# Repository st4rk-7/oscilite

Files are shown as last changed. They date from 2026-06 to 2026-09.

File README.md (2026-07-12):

# Oscilite

A digital storage oscilloscope built from scratch on an STM32F407. This project covers the full stack of building a real instrument: analog signal conditioning → ADC sampling → DMA → triggering → rendering → custom PCB hardware design.

Currently running as a breadboard prototype with the V2 custom PCB shield designed and ready for fabrication.

<div align="center">
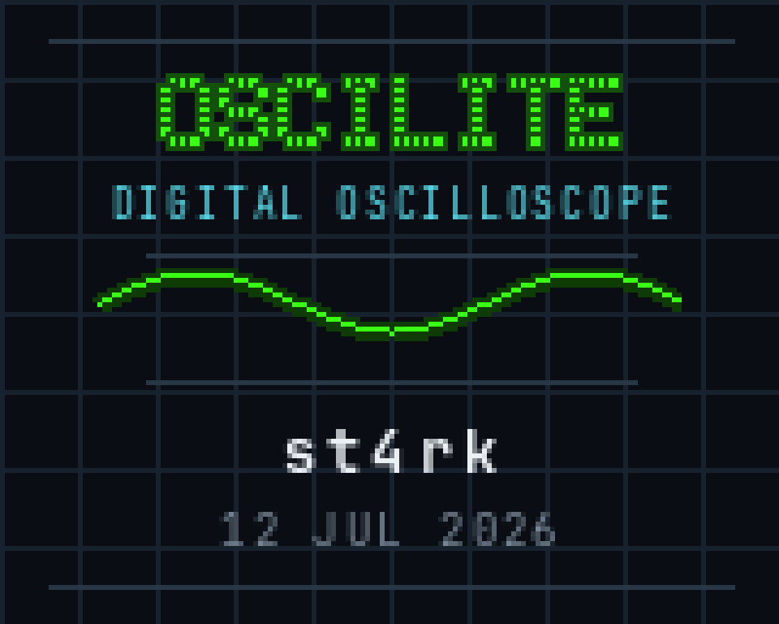
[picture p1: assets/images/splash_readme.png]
Oscilite boot splash
  
  <p><i>The boot splash rendered on the 160×128 ST7735 TFT at power-on.</i></p>
</div>

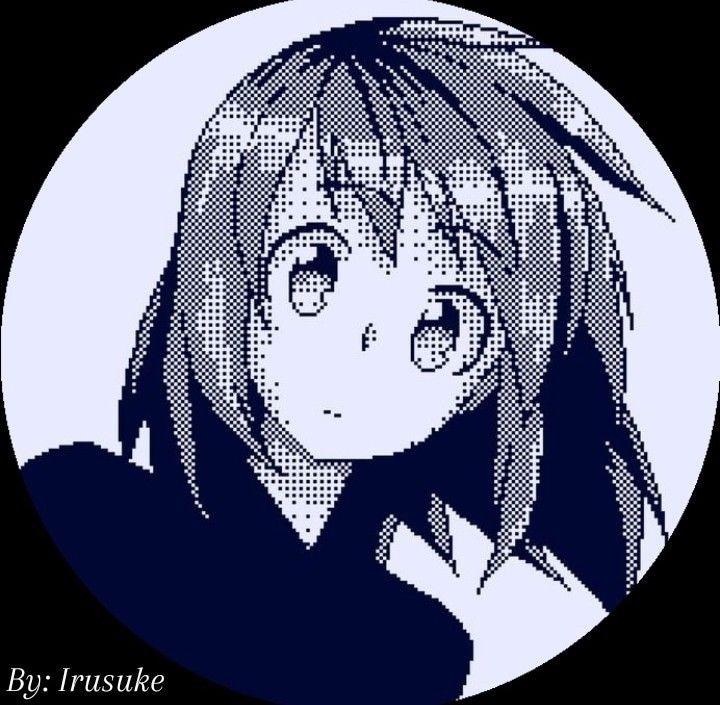
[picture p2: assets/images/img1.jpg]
Oscilite Breadboard Prototype

*The breadboard prototype running live firmware, capturing and displaying a waveform.*

## Features

- **Live waveform display** on an ILI9341 TFT with an 8×6 division graticule.
- **Hardware‑timed sampling** — a timer (TIM3) drives the ADC so every sample lands at a precise interval (timebase).
- **DMA capture** — the ADC streams samples into memory via DMA with zero CPU involvement (circular buffer on DMA2 Stream0).
- **Software triggering** — rising/falling slope with an adjustable trigger level, so the waveform locks in place instead of jittering.
- **Analog frontend** — attenuates and biases the input to safely measure bipolar signals (centered at ~1.65 V) into the MCU's 0–3.3 V ADC.
- **Automatic measurements** — min / max voltage, peak‑to‑peak, and signal frequency, shown on screen.
- **Boot splash screen** generated from an image via a custom Python pipeline.

## The Breadboard Prototype (V1)

The current working prototype proves out the entire software stack and analog theory.

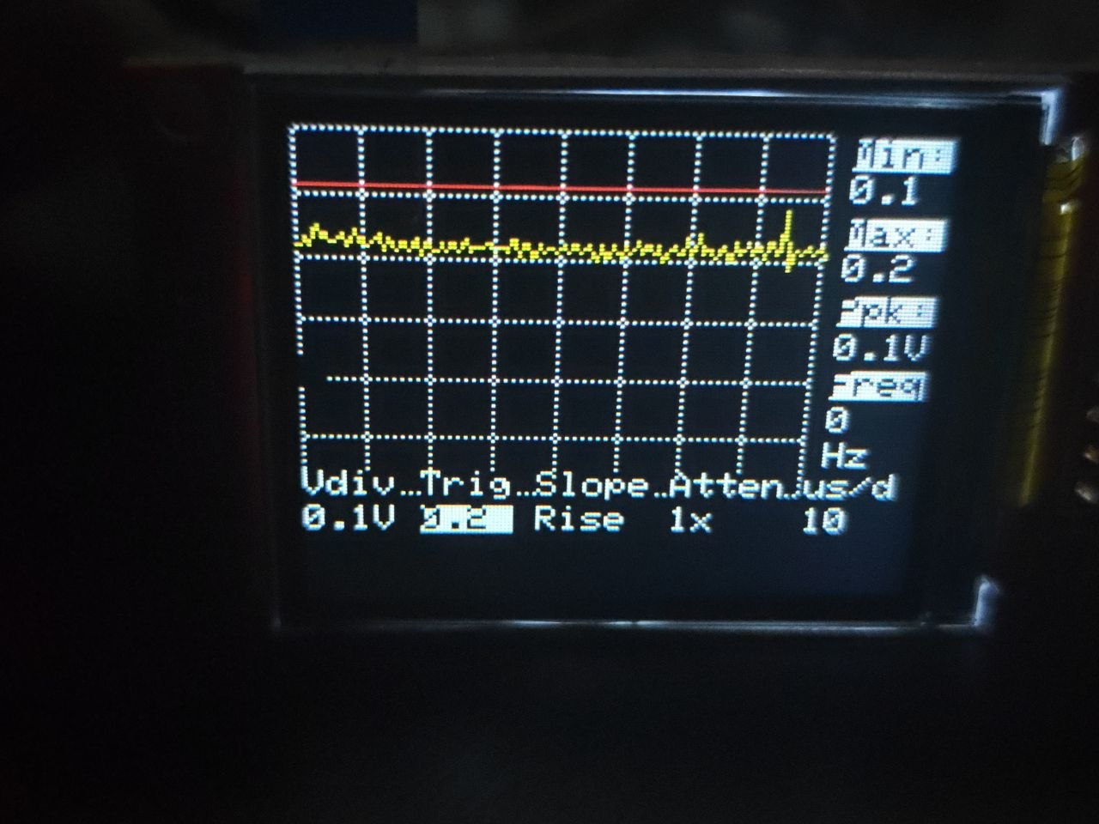
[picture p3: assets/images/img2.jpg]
Full System Setup

*Full system context showing the STM32F407 Discovery board, the analog frontend, and the display.*

**How It Works:**
```
 Input ─▶ Analog Frontend ─▶ ADC (12‑bit) ─▶ DMA ─▶ Sample Buffer ─▶ Trigger ─▶ Display
        (attenuate + bias)   (TIM3‑timed)   (circular)              (align)    (ILI9341)
```

The input signal is attenuated and centered at ~1.65 V using an MCP6002 op-amp buffer circuit so it fits the ADC's 0–3.3 V window. A timer fires the ADC at a fixed rate to set the timebase; the DMA engine moves each sample into a circular buffer without the CPU. The firmware then finds the trigger point (rising or falling through the trigger level) and draws the aligned waveform, computing min/max/Vpp and frequency along the way.

*(A deeper write‑up of the theory is in [`docs/HowItWorks.md`](docs/HowItWorks.md))*

## Hardware Design (V2 PCB)

To move past the breadboard stage, a custom 2-layer PCB shield was designed in KiCad 10. The shield mounts directly onto the STM32F407 dev board headers, carrying the analog frontend, BNC connector, user buttons, and a header for the TFT display.

<div align="center">
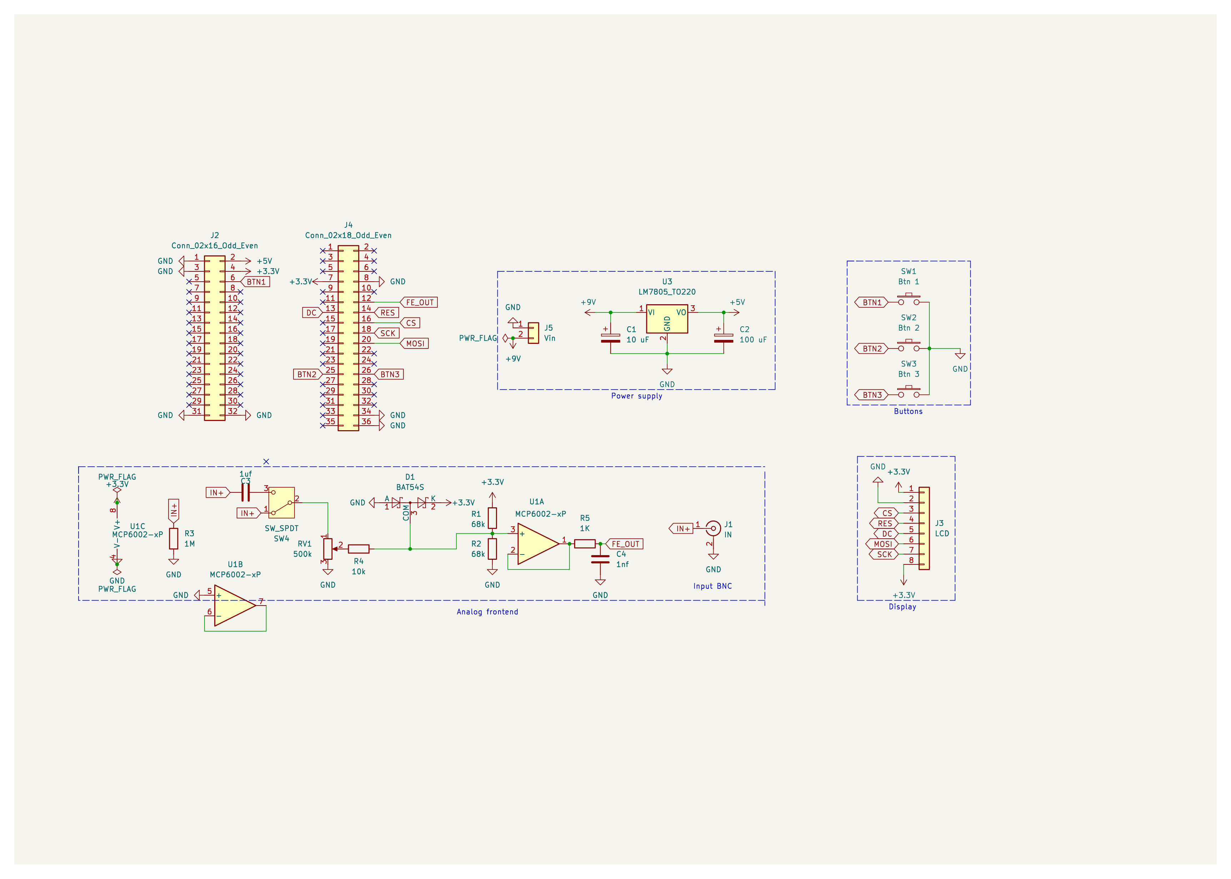
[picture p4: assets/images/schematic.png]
Oscilite Circuit Schematic
  
  <p><i>The analog frontend, power distribution, and UI circuitry.</i></p>
</div>

### PCB Layout and Renders
The board is fully routed, DRC-clean, and the Gerbers are ready for manufacturing.

| Top Copper & Silkscreen | 3D Render (Top) |
|:---:|:---:|
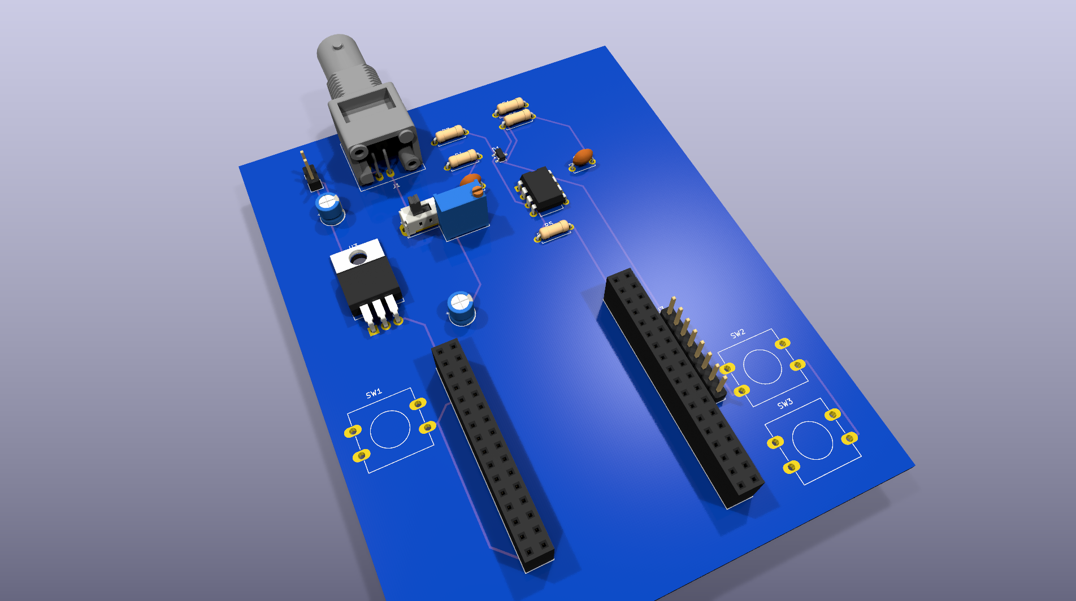
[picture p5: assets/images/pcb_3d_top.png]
|  |  |

| Bottom Copper | 3D Render (Bottom) |
|:---:|:---:|
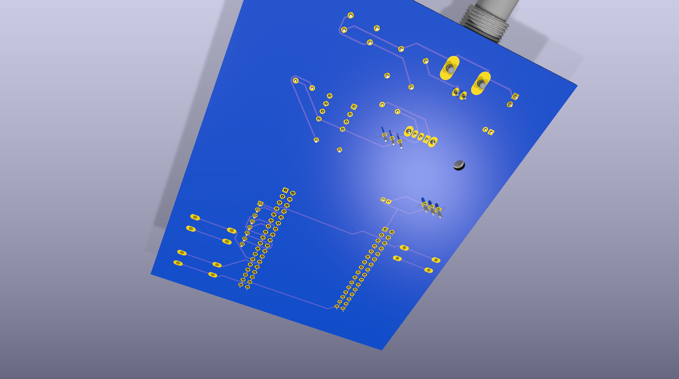
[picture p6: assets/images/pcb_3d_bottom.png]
|  |  |

*Note: The board relies on a dual-header layout designed specifically for the Diymore STM32F407VGT6 development board.*

## Project Structure

```
Core/Src/        Firmware: scope.c, ui.c, wave.c, adc.c, dma.c, tim.c, sandbox.c, main.c
Core/Inc/        Headers (scope.h defines grid, buffer length, trigger constants)
Drivers/         STM32 HAL + CMSIS + Display driver
pcb/fullScope/   KiCad project, layout, DRC reports, Gerbers
docs/            HowItWorks.md, PCB walkthrough
scripts/         Helper scripts (splash image conversion, UI patching)
Scopef407.ioc    STM32CubeMX configuration
```

## Building & Flashing

Prerequisites:
- [STM32CubeMX](https://www.st.com/en/development-tools/stm32cubemx.html) (config is in `Scopef407.ioc`)
- ARM GNU toolchain (`arm-none-eabi-gcc`)
- CMake ≥ 3.22 and Ninja
- A flashing tool: STM32CubeProgrammer, OpenOCD, or st-link

Build:
```bash
# Configure (uses the provided CMake presets)
cmake --preset Debug

# Build
cmake --build build/Debug
```

Flash it with your tool of choice, e.g.:
```bash
st-flash write build/Debug/Scopef407.bin 0x8000000
```

## Project Status & Phases

- **Phase 1 (Complete):** Breadboard prototype, firmware architecture (ADC/DMA/Trigger), and UI rendering.
- **Phase 2 (Current):** Custom PCB shield designed, DRC-verified, and Gerbers generated.
- **Phase 3 (Next):** PCB fabrication, assembly, and testing of the final standalone hardware unit.

This is intentionally a hands-on learning project to understand the full stack of instrument creation, not a precision lab tool.

## Acknowledgments
Built on the STM32 HAL and CMSIS.

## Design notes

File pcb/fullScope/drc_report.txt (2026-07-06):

** Drc report for fullScope.kicad_pcb **
** Created on 2026-06-18T18:27:12 **
** Report includes: Errors, Warnings **

** Found 19 DRC violations **
[solder_mask_bridge]: Front solder mask aperture bridges items with different nets
    Rule: board setup solder mask min width; error
    @(98.5000 mm, 108.0000 mm): PTH pad 1 [BTN1] of SW1
    @(100.0000 mm, 107.6200 mm): PTH pad 7 [unconnected-(J2-Pin_7-Pad7)] of J2
[solder_mask_bridge]: Rear solder mask aperture bridges items with different nets
    Rule: board setup solder mask min width; error
    @(100.0000 mm, 107.6200 mm): PTH pad 7 [unconnected-(J2-Pin_7-Pad7)] of J2
    @(98.5000 mm, 108.0000 mm): PTH pad 1 [BTN1] of SW1
[solder_mask_bridge]: Front solder mask aperture bridges items with different nets
    Rule: board setup solder mask min width; error
    @(98.5000 mm, 108.0000 mm): PTH pad 1 [BTN1] of SW1
    @(97.4600 mm, 107.6200 mm): PTH pad 8 [unconnected-(J2-Pin_8-Pad8)] of J2
[solder_mask_bridge]: Rear solder mask aperture bridges items with different nets
    Rule: board setup solder mask min width; error
    @(97.4600 mm, 107.6200 mm): PTH pad 8 [unconnected-(J2-Pin_8-Pad8)] of J2
    @(98.5000 mm, 108.0000 mm): PTH pad 1 [BTN1] of SW1
[solder_mask_bridge]: Front solder mask aperture bridges items with different nets
    Rule: board setup solder mask min width; error
    @(98.5000 mm, 113.0000 mm): PTH pad 2 [GND] of SW1
    @(97.4600 mm, 112.7000 mm): PTH pad 12 [unconnected-(J2-Pin_12-Pad12)] of J2
[solder_mask_bridge]: Front solder mask aperture bridges items with different nets
    Rule: board setup solder mask min width; error
    @(100.0000 mm, 112.7000 mm): PTH pad 11 [unconnected-(J2-Pin_11-Pad11)] of J2
    @(98.5000 mm, 113.0000 mm): PTH pad 2 [GND] of SW1
[solder_mask_bridge]: Rear solder mask aperture bridges items with different nets
    Rule: board setup solder mask min width; error
    @(98.5000 mm, 113.0000 mm): PTH pad 2 [GND] of SW1
    @(100.0000 mm, 112.7000 mm): PTH pad 11 [unconnected-(J2-Pin_11-Pad11)] of J2
[solder_mask_bridge]: Rear solder mask aperture bridges items with different nets
    Rule: board setup solder mask min width; error
    @(98.5000 mm, 113.0000 mm): PTH pad 2 [GND] of SW1
    @(97.4600 mm, 112.7000 mm): PTH pad 12 [unconnected-(J2-Pin_12-Pad12)] of J2
[hole_to_hole]: Drilled hole too close to other hole (board setup constraints min 0.2495 mm; actual 0.0000 mm)
    Rule: board setup constraints; error
    @(98.5000 mm, 108.0000 mm): PTH pad 1 [BTN1] of SW1
    @(97.4600 mm, 107.6200 mm): PTH pad 8 [unconnected-(J2-Pin_8-Pad8)] of J2
[hole_to_hole]: Drilled hole too close to other hole (board setup constraints min 0.2495 mm; actual 0.0000 mm)
    Rule: board setup constraints; error
    @(97.4600 mm, 112.7000 mm): PTH pad 12 [unconnected-(J2-Pin_12-Pad12)] of J2
    @(98.5000 mm, 113.0000 mm): PTH pad 2 [GND] of SW1
[copper_edge_clearance]: Board edge clearance violation
    Rule: board setup constraints edge; error
    @(74.0000 mm, 34.0000 mm): Rectangle on Edge.Cuts
    @(165.5000 mm, 136.0000 mm): PTH pad 1 [BTN3] of SW3
[copper_edge_clearance]: Board edge clearance violation
    Rule: board setup constraints edge; error
    @(74.0000 mm, 34.0000 mm): Rectangle on Edge.Cuts
    @(165.5000 mm, 141.0000 mm): PTH pad 2 [GND] of SW3
[copper_edge_clearance]: Board edge clearance violation
    Rule: board setup constraints edge; error
    @(74.0000 mm, 34.0000 mm): Rectangle on Edge.Cuts
    @(165.5000 mm, 120.0000 mm): PTH pad 1 [BTN2] of SW2
[copper_edge_clearance]: Board edge clearance violation
    Rule: board setup constraints edge; error
    @(74.0000 mm, 34.0000 mm): Rectangle on Edge.Cuts
    @(165.5000 mm, 125.0000 mm): PTH pad 2 [GND] of SW2
[courtyards_overlap]: Courtyards overlap
    Rule: board setup constraints courtyard; error
    @(86.0000 mm, 108.0000 mm): Footprint SW1
    @(100.0000 mm, 100.0000 mm): Footprint J2
[shorting_items]: Items shorting two nets (nets BTN1 and unconnected-(J2-Pin_7-Pad7))
    Local override; error
    @(98.5000 mm, 108.0000 mm): PTH pad 1 [BTN1] of SW1
    @(100.0000 mm, 107.6200 mm): PTH pad 7 [unconnected-(J2-Pin_7-Pad7)] of J2
[shorting_items]: Items shorting two nets (nets BTN1 and unconnected-(J2-Pin_8-Pad8))
    Local override; error
    @(98.5000 mm, 108.0000 mm): PTH pad 1 [BTN1] of SW1
    @(97.4600 mm, 107.6200 mm): PTH pad 8 [unconnected-(J2-Pin_8-Pad8)] of J2
[shorting_items]: Items shorting two nets (nets GND and unconnected-(J2-Pin_12-Pad12))
    Local override; error
    @(98.5000 mm, 113.0000 mm): PTH pad 2 [GND] of SW1
    @(97.4600 mm, 112.7000 mm): PTH pad 12 [unconnected-(J2-Pin_12-Pad12)] of J2
[shorting_items]: Items shorting two nets (nets GND and unconnected-(J2-Pin_11-Pad11))
    Local override; error
    @(98.5000 mm, 113.0000 mm): PTH pad 2 [GND] of SW1
    @(100.0000 mm, 112.7000 mm): PTH pad 11 [unconnected-(J2-Pin_11-Pad11)] of J2

** Found 4 unconnected pads **
[unconnected_items]: Missing connection between items
    Local override; error
    @(98.5000 mm, 113.0000 mm): PTH pad 2 [GND] of SW1
    @(86.0000 mm, 113.0000 mm): PTH pad 2 [GND] of SW1
[unconnected_items]: Missing connection between items
    Local override; error
    @(98.5000 mm, 113.0000 mm): PTH pad 2 [GND] of SW1
    @(100.0000 mm, 138.1000 mm): Track [GND] on B.Cu, length 2.5400 mm
[unconnected_items]: Missing connection between items
    Local override; error
    @(100.0000 mm, 100.0000 mm): Track [GND] on F.Cu, length 2.5400 mm
    @(98.5000 mm, 113.0000 mm): PTH pad 2 [GND] of SW1
[unconnected_items]: Missing connection between items
    Local override; error
    @(98.5000 mm, 108.0000 mm): PTH pad 1 [BTN1] of SW1
    @(94.5400 mm, 108.0000 mm): Track [BTN1] on B.Cu, length 4.1295 mm

** Found 0 Footprint errors **

** Ignored checks **
    - Footprint has no courtyard defined
    - Track endpoint not centered on via
    - Tuning profile track geometries
    - Footprint doesn't match symbol's footprint filters
    - Silkscreen clearance
    - Silkscreen clipped by solder mask
    - PTH inside courtyard
    - NPTH inside courtyard

** End of Report **

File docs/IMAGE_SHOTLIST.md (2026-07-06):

# Oscilite — Image Shot List

Capture list for the README + LinkedIn / GitHub / portfolio publish.
Goal: show it **works**, show it's **real hardware**, and show the **engineering depth** (firmware → analog → PCB → fab).

Save everything into `assets/images/`. Suggested final filenames are in each item.
Existing files: `img1.jpg`, `img2.jpg` (re-slot or rename into the list below).

> **⚠️ No physical STM32 on hand right now.** Everything in **GROUP A** below is
> generated on your computer (KiCad, diagrams) and can be captured *today* — that
> covers all of TIER 1 except the live-screen photo, plus most depth shots.
> Everything in **GROUP B** needs the powered-up board and waits until you have it.
> You can publish a strong README/portfolio post with Group A alone; add Group B later.

---

## ✅ GROUP A — Capturable now (no hardware needed)

These are the high-value, "real engineering" shots and they're all free to produce:

- [ ] **PCB 3D render — top** — `pcb_3d_top.png`
  KiCad → open `pcb/fullScope/fullScope.kicad_pcb` → View → **3D Viewer** (Alt+3) → File → Export Current View → PNG. Use this as the **hero image** until you have a real photo.

- [ ] **PCB 3D render — bottom** — `pcb_3d_bottom.png`
  In the 3D viewer, drag to flip the board. Shows bottom-copper (blue) routing.

- [ ] **PCB 2D layout (routed)** — `pcb_layout.png`
  KiCad PCB editor, all copper layers on, traces visible. Screenshot or File → Export → SVG/PNG. Shows the routing work.

- [ ] **Schematic overview** — `schematic.png`
  From `fullScope.kicad_sch`: File → Plot → PDF (or screenshot the sheet). Signals "designed circuit, not a breadboard hack."

- [ ] **Analog frontend close-up** — `frontend.png`
  Crop just the frontend section of the schematic (±3.3V attenuator / op-amp / 1.65V bias). The cleverest electronics in the project. (Also see `docs/frontend.pdf`.)

- [ ] **Gerber / fab preview** — `gerber_preview.png`
  Upload `pcb/fullScope/fullScope_gerbers.zip` to an online viewer (JLCPCB preview, or use KiCad's Gerber Viewer) and screenshot. Proves it's manufacturing-ready.

- [ ] **Block diagram** — `block_diagram.png`
  Signal flow: `Input → Analog Frontend → ADC → DMA → Buffer → Display`. Make in draw.io / Excalidraw. The single most useful image for a reader skimming the README — and the README already has this as ASCII, so you're just prettifying it.

- [ ] **(Optional) DRC clean screenshot** — `drc_clean.png`
  KiCad → Inspect → Design Rules Checker → Run. Screenshot the "0 violations" result. Strong credibility for an embedded/hardware portfolio.

> With Group A you have: a hero (3D render), the layout, schematic, frontend, fab proof,
> and a diagram — enough for a complete README and LinkedIn carousel **today**.

---

## ⏳ GROUP B — Needs the physical board (capture later)

- [ ] **Hero shot (real)** — `hero.jpg` — assembled scope powered on showing a waveform. Swap in over the 3D render once you have it.
- [ ] **Live waveform close-up** — `waveform_screen.jpg` — display showing a trace + grid. Feed a 1 kHz square from a function gen or another MCU PWM pin.
- [ ] **Wiring / bring-up shot** — `bringup.jpg` — STM32F407 + display + frontend on jumper wires. `img1.jpg`/`img2.jpg` may already be this — check them.
- [ ] **UI / menu shot** — `ui_menu.jpg` — on-screen timebase/volt/trigger controls.
- [ ] **Splash screen** — `splash.jpg` — the boot splash (from your `splash.h` + `img2splash.py` pipeline).
- [ ] **Trigger demo (2 photos)** — `trigger_unstable.jpg` / `trigger_stable.jpg` — same signal, trigger off vs on. Great LinkedIn carousel.
- [ ] **Multiple waveforms grid** — `waveforms_montage.jpg` — sine/square/triangle/noise, 2x2.
- [ ] **Size/scale shot** — `scale.jpg` — board next to a coin/hand.

> **Check `assets/images/img1.jpg` and `img2.jpg` first** — if they're already bench/bring-up
> photos, you may already have part of Group B covered.

---

## (original tiers, for reference)

## TIER 1 — Must have (the README cannot land without these)

- [ ] **Hero shot** — `hero.jpg`
  The assembled scope powered on, displaying a clean waveform (sine or square). Slightly angled, good lighting, plain background. This is the LinkedIn thumbnail and the top of the README. Make it the best photo you take.

- [ ] **Live waveform close-up** — `waveform_screen.jpg`
  Tight shot of the display showing a recognizable trace with the grid/graticule visible. Proves the DSO actually samples and renders. Feed it a known signal (e.g. 1 kHz square from a function gen or another MCU PWM pin).

- [ ] **PCB 3D render — top** — `pcb_3d_top.png`
  KiCad → View → **3D Viewer** → export PNG. Top of `pcb/fullScope/fullScope.kicad_pcb`. Looks professional and costs nothing to produce.

- [ ] **PCB 2D layout (routed)** — `pcb_layout.png`
  KiCad PCB editor, all copper layers visible, traces routed. Export via File → Export → SVG/PNG, or screenshot. Shows the 179-trace routing work.

---

## TIER 2 — Strongly recommended (depth + credibility)

- [ ] **PCB 3D render — bottom** — `pcb_3d_bottom.png`
  Flip side in 3D viewer. Shows the bottom-copper (blue) routing.

- [ ] **Schematic overview** — `schematic.png`
  Export the full sheet from `fullScope.kicad_sch` (File → Plot → PDF, or screenshot). Even as a thumbnail it signals "this is a designed circuit, not a breadboard hack."

- [ ] **Analog frontend close-up** — `frontend.png`
  Crop of just the analog-frontend section of the schematic (the ±3.3V attenuator / op-amp / 1.65V bias). This is the cleverest electronics in the project — call it out. (Ref: `docs/frontend.pdf` mentioned in HowItWorks.md.)

- [ ] **Wiring / bring-up shot** — `bringup.jpg`
  STM32F407 + display + frontend wired on the bench (jumper wires / dev board stage). Tells the "before the PCB" story. `img1.jpg`/`img2.jpg` may already be this.

- [ ] **UI / menu shot** — `ui_menu.jpg`
  The on-screen UI: timebase / voltage / trigger controls or the menu. Shows it's a usable instrument, not just a trace renderer.

- [ ] **Splash screen** — `splash.jpg`
  The boot splash on the display. You built a `splash.h` + `img2splash.py` pipeline — worth a sentence and a photo.

---

## TIER 3 — Nice to have (storytelling / extra polish)

- [ ] **Trigger demo (2 photos)** — `trigger_stable.jpg`, `trigger_unstable.jpg`
  Same signal, trigger off vs on (jittery trace vs locked trace). Great for a LinkedIn carousel — visually demonstrates what triggering does.

- [ ] **Multiple waveforms grid** — `waveforms_montage.jpg`
  Sine / square / triangle / noise in a 2x2 montage. Shows range. Good portfolio filler.

- [ ] **Size/scale shot** — `scale.jpg`
  Scope next to a coin or hand for sense of scale. Humanizes the build.

- [ ] **Gerber / fab preview** — `gerber_preview.png`
  Screenshot of the gerbers in an online viewer (e.g. JLCPCB upload preview or KiCad gerber viewer). Proves it's manufacturing-ready.

- [ ] **Block diagram** — `block_diagram.png`
  Signal flow: `Input → Analog Frontend → ADC → DMA → Buffer → Display`. Make in draw.io / Excalidraw. The single most useful image for a reader skimming the README. (Optional but high value.)

---

## Capture tips
- **One consistent background + lighting** for all physical photos → looks like a deliberate project, not random snaps.
- Shoot landscape (16:9) — fits README and LinkedIn better than portrait.
- For screen photos: dim room, lower display brightness slightly, focus on the screen to avoid moire/glare.
- KiCad renders export at high res for free — lean on them; they carry the README even before you reshoot hardware photos.

## Where they go
- **README hero block:** `hero.jpg` + one-line tagline.
- **"It works" section:** `waveform_screen.jpg`, `ui_menu.jpg`, trigger demo.
- **"Hardware design" section:** `pcb_3d_top.png`, `pcb_layout.png`, `schematic.png`, `frontend.png`.
- **"How it works" section:** `block_diagram.png` (pairs with `docs/HowItWorks.md`).
- **LinkedIn post:** lead with `hero.jpg`, then a 3–5 image carousel (waveform, PCB 3D, schematic, trigger demo).

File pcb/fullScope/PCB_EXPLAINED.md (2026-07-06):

# pillScopePlus PCB — Everything Explained (Beginner's Guide)

This document explains, in plain language, everything that happened to turn your
oscilloscope schematic into a finished, manufacturable circuit board — starting
from the moment you were hand-drawing red traces, all the way to the Gerber files
ready for the factory.

Read it top to bottom. Each section builds on the last. If anything is unclear,
ask and we'll expand it.

---

## 0. The big picture: what is a PCB and what were we doing?

A **PCB (Printed Circuit Board)** is the green (or any color) board inside every
electronic device. Instead of connecting parts with loose wires, a PCB has thin
lines of copper baked onto it that carry electricity between the components.

Designing one has a fixed workflow. We had already done the first parts before
today:

1. **Schematic** — a diagram of *what connects to what* (done earlier).
2. **Footprints** — telling the software the real physical size/shape of each part (done earlier).
3. **Placement** — arranging the parts physically on the board ← *we redid this today*.
4. **Routing** — drawing the copper lines that connect the parts ← *the big job today*.
5. **DRC** — an automatic check that the board has no mistakes ← *today*.
6. **Gerbers** — the final files you send to the factory ← *today*.

You were stuck partway through step 4 (routing). Today we finished steps 3–6.

---

## 1. The vocabulary you asked about

Before the story, here are the words. Keep coming back to this section.

### Layers: F.Cu, B.Cu, Edge.Cuts

A PCB is like a sandwich with multiple layers. Yours is a **2-layer board** — it
has copper on the **top** and on the **bottom**. The software draws each layer in
a different color:

| Name | Means | Color on screen | What it is |
|---|---|---|---|
| **F.Cu** | **F**ront **Cu** (copper) | **Red** | The copper wiring on the **top** of the board |
| **B.Cu** | **B**ack **Cu** (copper) | **Blue** | The copper wiring on the **bottom** of the board |
| **Edge.Cuts** | Edge / cuts | **Yellow** | The *outline* — where the factory physically cuts the board out |

> **"Cu"** is the chemical symbol for copper. That's why copper layers end in `.Cu`.

So when you asked **"why are some wires blue?"** — those blue lines are traces on
the **bottom** copper layer (B.Cu). The red ones are on the **top** (F.Cu). Having
two layers means wires can cross each other without touching: one goes over the
top, the other underneath, like a road bridge over another road.

### Trace (a.k.a. track)

A **trace** is one line of copper that carries electricity from one point to
another. It replaces a wire. "Routing" = drawing all the traces.

### Pad

A **pad** is the little metal spot where a component's leg gets soldered. Traces
connect pad to pad. On your board most pads are **through-hole** — they have a
drilled hole so a component leg pokes through and is soldered on the back.

### Ratsnest (the thin lines you saw before routing)

Before you route, the software draws thin straight "rubber-band" lines showing
*which pads need to be connected*. These are called the **ratsnest** (or airwires).
They are **not** real wires — just hints. Your whole routing job was to replace
each thin ratsnest line with a real copper trace. When you draw the trace, the
matching ratsnest line disappears.

### Net

A **net** is a group of pads that all need to be connected together (because the
schematic says so). For example, every pad that should connect to "+3.3V" is on
the `+3.3V` net. "GND" is the net for ground. Routing = connecting every pad on
each net with copper.

---

## 2. The story, step by step (from your red traces to the finish)

### Where you started: hand-drawing red traces

When you pressed **`X`** in KiCad and clicked pad-to-pad, you were **manually
routing** — drawing copper traces by hand, one at a time. The red line that
appeared was a real trace on the top copper layer (F.Cu). You successfully
connected a few (like the +3.3V trace) — that proved you understood the idea:
**trace over each ratsnest line, pad to pad.**

### The problem we hit: bad placement made routing impossible

You found that many traces were impossible to route cleanly. **This was not your
fault.** The components were arranged badly. Two specific problems:

- The **display header (J3)** was on the far *left* of the board, but every wire
  it needed went to **J4 on the right** — so 6 wires had to cross the *entire*
  board.
- Two **buttons (SW2, SW3)** were on the left, but their signals went to J4 on
  the right too.

When parts that connect to each other are far apart, their wires cross everything
and tangle. The professional rule is: **good placement makes routing easy; bad
placement makes it impossible.** So we fixed the placement first.

### What I did: re-organized the components (Step 3 redone)

I rearranged all 22 components into logical **clusters**, so parts that connect to
each other sit near each other:

- **Power section** (voltage regulator + capacitors) grouped in the top-left.
- **Analog frontend** (the BNC input → op-amp chain) flowing left-to-right across
  the top.
- **Display header (J3)** moved right next to **J4** — killing those 6 cross-board wires.
- **Buttons** moved next to the headers they connect to.

This is why the tangle calmed down dramatically after the re-placement.

### Then: auto-routing with Freerouting (Step 4 finished)

Instead of you hand-drawing all ~19 connections, we used a program called
**Freerouting** to draw all the copper traces automatically. (Explained in detail
in Section 5.) It routed the whole board in about 2 seconds — that's the **179
traces**, both red (top) and blue (bottom), now on your board.

### Why I asked you to make changes twice

You asked why I made you redo things twice. Here's the honest answer:

When I first re-placed the components, I **underestimated the physical size of the
buttons**. A push-button is about 12 mm wide with pads sticking out 14 mm from its
anchor point — bigger than my first estimate. So:

- **1st fix:** A button (SW1) ended up physically *overlapping* the J2 header —
  their holes literally landed on the same spot. The DRC check caught it. I moved
  the buttons away and we re-routed.
- **2nd fix:** After that, two buttons (SW2, SW3) were still only 10 mm apart, but
  they need ~15 mm so their bodies don't physically collide. DRC caught that too.
  I spaced them out and we re-routed one last time.

Each time we moved parts, the old traces no longer lined up, so we had to re-route
— that's why you exported/imported a few times. It wasn't wasted; it was the
normal "check → fix → re-check" loop that catches real manufacturing problems
*before* you spend money. The end result: a board with **zero errors**.

### Finally: DRC clean → Gerbers exported (Steps 5 & 6)

After the last fix, the automatic check (DRC) reported **0 errors and 0 missing
connections**. That was our agreed stopping point. Then I exported the **Gerber**
files (Section 8) — the package you send to a factory like JLCPCB.

---

## 3. What did you do with the grounds? (your question)

**Ground (GND)** is the common "0 volts" reference that almost every part connects
to — it's the single biggest net on any board (tons of pads need ground).

There are two ways to connect all the ground pads:

1. **Route them as traces** — draw a copper line to each ground pad like any other
   net.
2. **Copper pour** — flood a whole area of the board with copper and let every
   ground pad touch it (Section 7).

**What we actually did:** Freerouting connected all the ground pads using normal
**traces** (option 1). The DRC check confirmed every single ground pad is properly
connected (0 unconnected). So ground is *fully handled*.

Earlier in the process I had planned to use a copper pour for ground (option 2),
which is why you saw "ground pour" in our step list. But since the auto-router
already connected every ground pad with traces, **the pour became unnecessary** —
the board is complete and correct without it. A pour would be a nice-to-have for
noise reduction, not a requirement. We correctly skipped it.

---

## 4. Why are some wires blue? (your question)

Because your board has **two copper layers**, and the software color-codes them:

- **Red wires = top copper (F.Cu)**
- **Blue wires = bottom copper (B.Cu)**

When two wires need to cross without touching, the router puts one on top (red)
and one on the bottom (blue) so they pass over/under each other — like a highway
overpass. On your through-hole board, the component legs go through the whole
board, so a trace can connect on either the red or the blue layer at the same pad
without needing extra holes. That's why there are no "vias" (layer-change holes) —
the through-hole pads already bridge both layers.

---

## 5. What is Freerouting and what is it used for? (your question)

**Freerouting** is a free, open-source **auto-router** — a program that draws all
the copper traces on a PCB automatically, so you don't have to click each one by
hand.

### Why we used it

Hand-routing your board meant manually drawing ~19 connections, and you found it
slow and frustrating ("super clunky"). An auto-router does the same job in
seconds. With your now-clean placement, it did an excellent job.

### How it works (the DSN → SES dance)

Freerouting is a separate program from KiCad, so they hand files back and forth:

1. **KiCad exports a `.dsn` file** (`File → Export → Specctra DSN`). This `.dsn`
   describes your board to Freerouting: where every pad is, the board outline, and
   which pads need connecting (the nets). Think of it as "here's the puzzle."
2. **Freerouting reads the `.dsn`, solves the routing**, trying thousands of trace
   paths until everything is connected without crossings or rule violations. I ran
   this on the command line:
   `java -jar freerouting.jar -de fullScope.dsn -do fullScope.ses`
3. **Freerouting writes a `.ses` file** (a "session" file). This is its *answer* —
   the list of all the trace paths it figured out.
4. **KiCad imports the `.ses`** (`File → Import → Specctra Session`), which draws
   all those traces onto your real board.

That's the whole loop: **KiCad → .dsn → Freerouting → .ses → KiCad.** Every time
we moved components, we ran this loop again so the routing matched the new
positions.

> **"java -jar"**: Freerouting is written in the Java language, so it runs with the
> `java` command. You already had Java installed, which is why it worked.

---

## 6. How my "automation scripting" works (your question)

A KiCad PCB file (`fullScope.kicad_pcb`) is actually a **text file**. If you open
it in a text editor, it's a long list describing every component, its position,
every trace, etc., written in a format with lots of parentheses, like:

```
(footprint "Button"
    (at 78 104)        ← this line is the component's X,Y position
    ...
)
```

Because it's text, I can read and edit it with small **scripts** (tiny programs,
written in Python). Here's what I used scripting for:

- **Reading the board:** my scripts scanned the file to list every component, its
  position, its pads, and which net each pad belongs to. That's how I figured out
  the "J3 is far from J4" problem mathematically.
- **Re-placing components:** to move a part, my script found its `(at X Y)` line
  and changed the numbers. Moving 22 components by hand would be slow and
  error-prone; a script does it instantly and exactly.
- **Checking for overlaps:** before applying a new layout, my script calculated
  each component's real size and checked that none would physically collide — so
  we'd catch problems *before* opening KiCad.
- **Clearing old traces:** when we re-placed parts, the old traces were wrong, so a
  script deleted all the `(segment ...)` lines (each trace is a "segment") to give
  a clean slate for re-routing.

> **Important caution we respected:** editing the file directly is powerful but
> risky — one wrong character can corrupt the board. That's why I always made a
> **backup first** (you'll see `.bak_...` files in the folder), and why we did the
> *routing* with Freerouting + the KiCad GUI rather than hand-writing traces into
> the file. We even tested it: I tried writing one trace directly into the file,
> it didn't take (your KiCad version uses a new format), so we wisely switched to
> the GUI/Freerouting approach instead.

---

## 7. What does "pouring" / copper pour mean? (your question)

A **copper pour** (also called a "filled zone" or "ground plane") is when you
flood an entire region of the board with a solid sheet of copper, instead of thin
traces.

It's mainly used for **ground**. Instead of running a separate ground trace to
every part, you pour copper across the whole board and every ground pad just
touches it. Benefits:

- Every ground pad connects automatically.
- The big copper sheet reduces electrical noise (good for sensitive analog parts
  like your op-amp).

**We did not need it** on your board, because the auto-router already connected
every ground pad with traces (see Section 3). The board is complete without a
pour. You could add one later as a polish step, but it's optional.

---

## 8. What is DRC? What is a drill file? What are Gerbers? (your questions)

These are the final three concepts — the "is it correct?" check and the "send to
factory" files.

### DRC — Design Rule Check

**DRC** is an automatic inspector. You press a button and the software checks your
whole board against the manufacturing rules and reports every mistake, such as:

- Two traces too close together (could short circuit).
- A drilled hole too close to another hole.
- A connection that was never routed (a "missing wire").
- A part hanging off the edge of the board.

**This is what caught the button problems.** Each time, DRC told us exactly what
was wrong and where. When DRC finally reported **"0 violations, 0 unconnected
items,"** it meant the board is electrically correct and manufacturable. That was
our finish line.

### Drill file

The factory needs to know **where to drill holes** (for every through-hole part
leg) and **how big** each hole is. The **drill file** (`fullScope.drl`) is a list
of all those hole positions and sizes. The drilling machine reads it directly.

### Gerbers

**Gerber files** are the universal language of PCB factories. Each Gerber file
describes **one layer** of your board as precise shapes the factory machines can
reproduce. Your export produced one file per layer, including:

| File ending | What it describes |
|---|---|
| `.gtl` / `-F_Cu` | Top copper (the red traces) |
| `.gbl` / `-B_Cu` | Bottom copper (the blue traces) |
| `.gts` / `.gbs` | Solder mask (the green coating, with gaps at pads) |
| `.gto` / `.gbo` | Silkscreen (the white text/labels) |
| `.gm1` / `-Edge_Cuts` | The board outline (where to cut) |
| `.drl` | The drill holes |

Together, these files are a complete recipe for building your exact board. I
bundled them into **`fullScope_gerbers.zip`** — that single zip is what you upload
to a manufacturer like JLCPCB, and they ship you the physical board.

---

## 9. Where things stand & what's left

- ✅ Board is fully placed, routed, and **passes DRC with zero errors**.
- ✅ Gerbers + drill files are exported and zipped:
  `pcb/fullScope/fullScope_gerbers.zip`
- ⚠️ **Before ordering:** measure the real distance between the two pin-header rows
  on your physical Diymore STM32 board with calipers, and confirm the J2↔J4
  spacing matches (~35.6 mm was an estimate). This is the one thing we couldn't
  verify without the board in hand. See `FABRICATION_TODO.md`. If it's off, the
  board won't plug together.

That's the entire journey. You took a circuit from a schematic to a
factory-ready board — placement, routing, verification, and output files. That's
the full PCB design skill in miniature.

---

## 10. Quick glossary (one-line reminders)

- **PCB** — the physical circuit board.
- **Trace / track** — a copper line that connects parts (replaces a wire).
- **Pad** — metal spot where a part is soldered.
- **Net** — a group of pads that must be connected (e.g. GND, +3.3V).
- **Ratsnest** — thin hint-lines showing what still needs connecting.
- **F.Cu (red)** — top copper layer. **B.Cu (blue)** — bottom copper layer.
- **Edge.Cuts (yellow)** — the board outline.
- **Placement** — arranging components physically.
- **Routing** — drawing the traces.
- **Freerouting** — a program that routes automatically.
- **DSN / SES** — the files KiCad and Freerouting exchange.
- **Copper pour** — a solid sheet of copper, usually for ground.
- **DRC** — automatic error check of the whole board.
- **Drill file** — list of hole positions/sizes.
- **Gerbers** — the per-layer files you send to the factory.
- **Via** — a small plated hole that moves a trace between layers (your board
  didn't need any, because through-hole pads already bridge both layers).

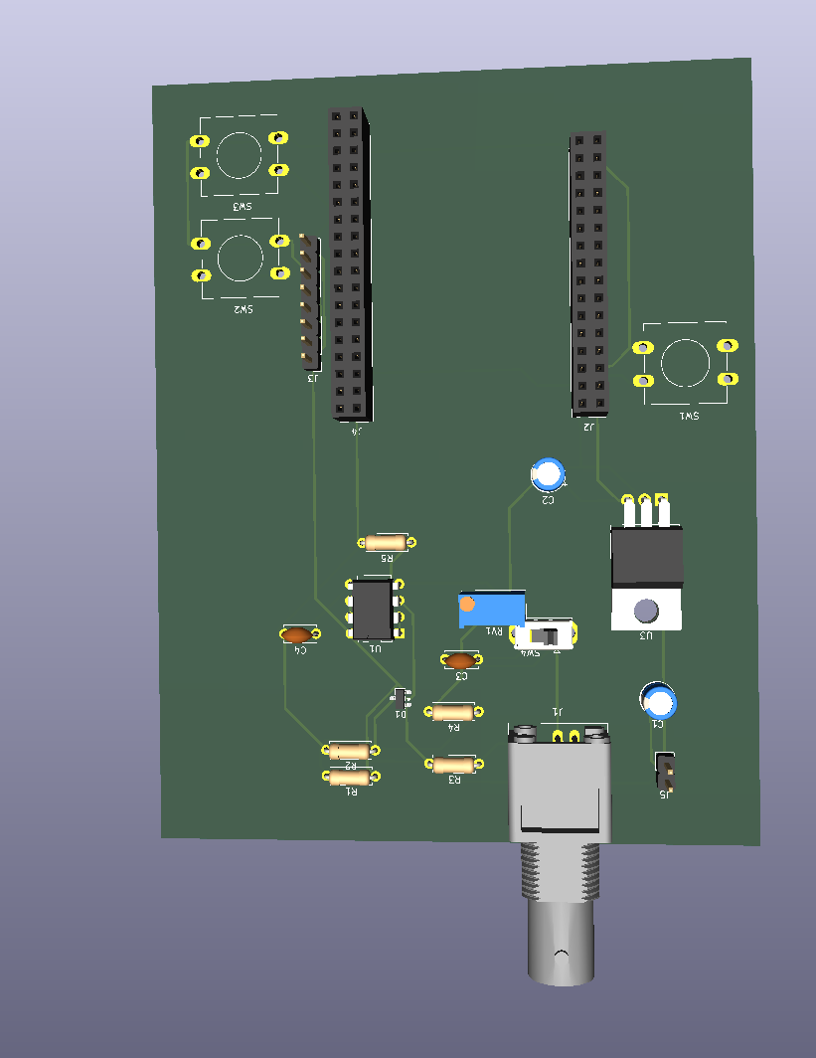
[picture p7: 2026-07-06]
pcb/fullScope/imgs/fullScope.png

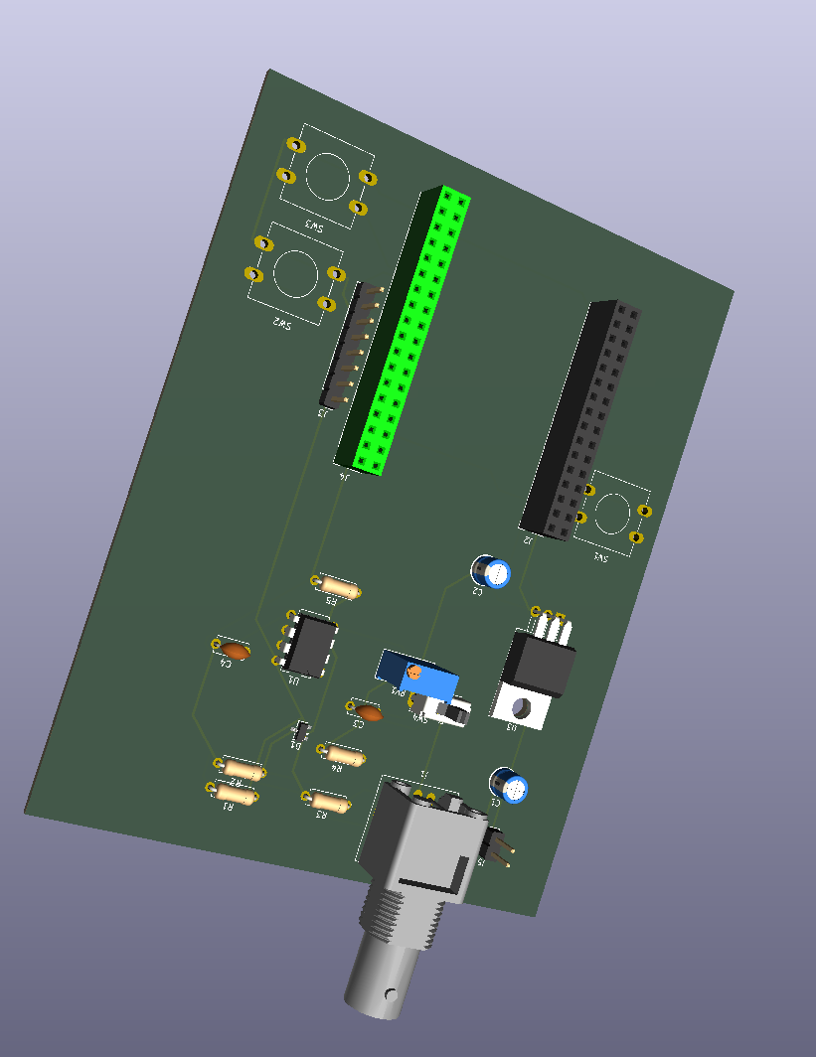
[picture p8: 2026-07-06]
pcb/fullScope/imgs/fullScope2.png

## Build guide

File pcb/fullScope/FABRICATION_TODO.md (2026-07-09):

# FABRICATION TODO — Header Spacing Fix Required

## Measured vs. PCB values

| Dimension | PCB file (current) | Measured (real board) | Delta |
|---|---|---|---|
| J2↔J4 center-to-center | 35.56 mm | **38.1 mm** | **+2.54 mm (1 pitch)** |

The PCB was laid out one pin pitch too narrow. The board **will not seat** without this fix.

## Fix steps (KiCad GUI, ~10 min)

1. Open `fullScope.kicad_pcb` in KiCad PCB editor.
2. Select J4 → press `E` → change X from `135.56` to `138.1`. Hit OK.
3. Reconnect the 15 broken traces (thin white ratsnest lines). Press `X` to route.
4. Run DRC: Inspect → Design Rules Checker → 0 violations.
5. Re-export Gerbers: File → Fabrication Outputs → Gerbers.
6. Re-zip and replace `fullScope_gerbers.zip`.

## Other dimensions (confirmed safe)

- Pin pitch: 2.54 mm (standard)
- Row-to-row inside each header: 2.54 mm (standard dual-row)
- Board size: 45 mm x 60 mm

## After fix — order checklist

- [ ] J4 moved to X=138.1
- [ ] DRC clean (0 violations)
- [ ] Gerbers re-exported
- [ ] Upload to JLCPCB/PCBWay and verify preview
- [ ] Order

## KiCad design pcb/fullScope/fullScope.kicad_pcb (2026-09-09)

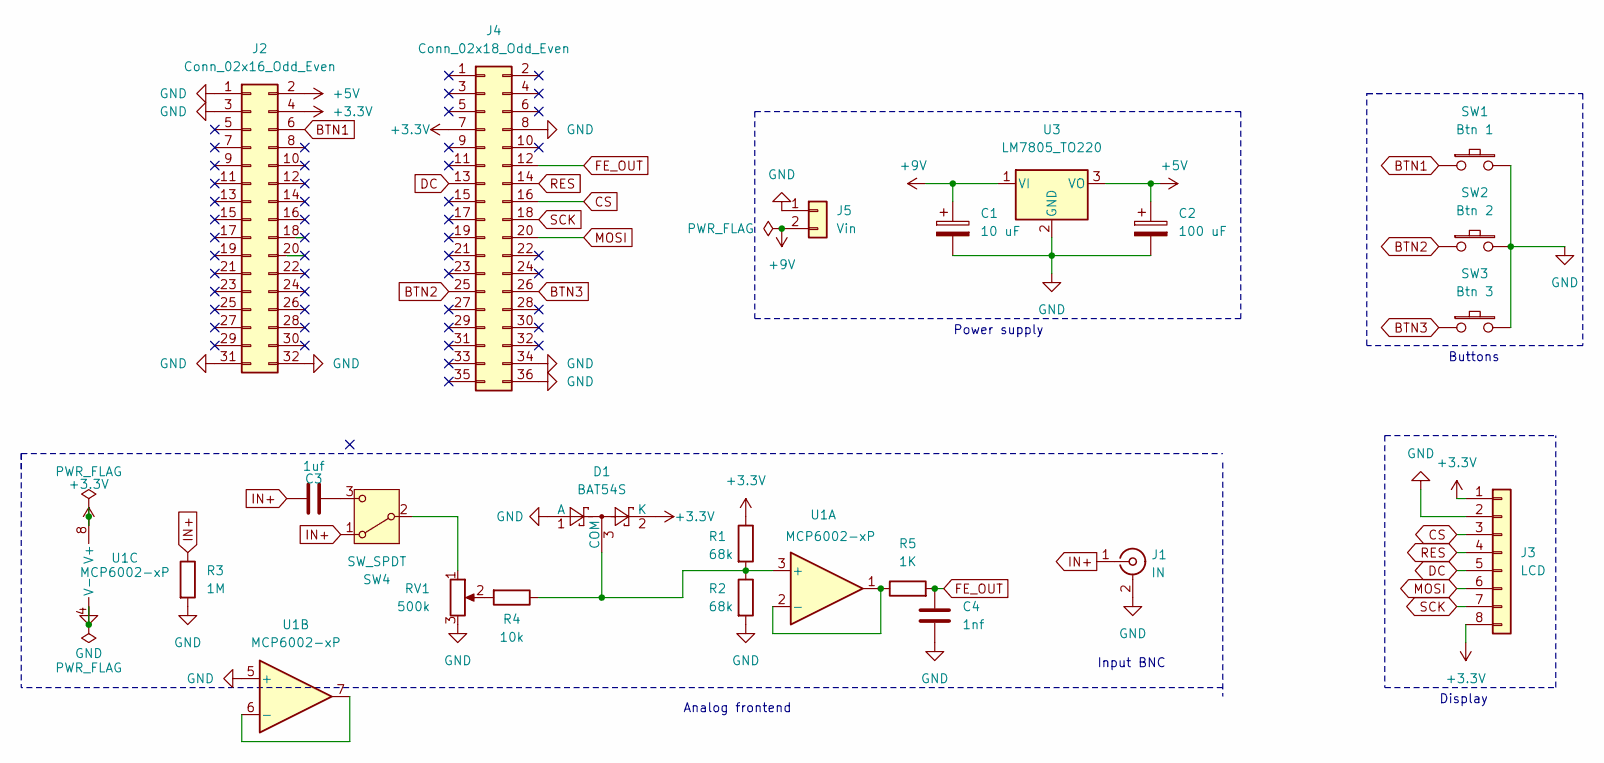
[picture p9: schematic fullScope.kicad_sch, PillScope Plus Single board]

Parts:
C1: 10 uF; CP_Radial_D5.0mm_P2.00mm
C2: 100 uF; CP_Radial_D5.0mm_P2.00mm
C3: 1uf; C_Disc_D5.0mm_W2.5mm_P5.00mm
C4: 1nf; C_Disc_D5.0mm_W2.5mm_P5.00mm
D1: BAT54S; SOT-23
J1: IN; BNC_Amphenol_B6252HB-NPP3G-50_Horizontal
J2: Conn_02x16_Odd_Even; PinSocket_2x16_P2.54mm_Vertical
J3: LCD; PinHeader_1x08_P2.54mm_Vertical
J4: Conn_02x18_Odd_Even; PinSocket_2x18_P2.54mm_Vertical
J5: Vin; PinHeader_1x02_P2.54mm_Vertical
R1, R2: 68k; R_Axial_DIN0207_L6.3mm_D2.5mm_P7.62mm_Horizontal
R3: 1M; R_Axial_DIN0207_L6.3mm_D2.5mm_P7.62mm_Horizontal
R4: 10k; R_Axial_DIN0207_L6.3mm_D2.5mm_P7.62mm_Horizontal
R5: 1K; R_Axial_DIN0207_L6.3mm_D2.5mm_P7.62mm_Horizontal
RV1: 500k; Potentiometer_Bourns_3296W_Vertical
SW1: Btn 1; SW_PUSH-12mm
SW2: Btn 2; SW_PUSH-12mm
SW3: Btn 3; SW_PUSH-12mm
SW4: SW_SPDT; SW_Slide_SPDT_Straight_CK_OS102011MS2Q
U1: MCP6002-xP; DIP-8_W7.62mm
U3: LM7805_TO220; TO-220-3_Horizontal_TabDown

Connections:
+3.3V: D1.2 (K), J2.4, J3.1, J3.8, J4.7, R1.1, U1.8 (V+)
+5V: C2.1, J2.2, U3.3 (VO)
+9V: C1.1, J5.2, U3.1 (VI)
BTN1: J2.6, SW1.1
BTN2: J4.25, SW2.1
BTN3: J4.26, SW3.1
CS: J3.3, J4.16
DC: J3.5, J4.13
FE_OUT: C4.1, J4.12, R5.2
GND: C1.2, C2.2, C4.2, D1.1 (A), J1.2 (Ext), J2.1, J2.3, J2.31, J2.32, J3.2, J4.8, J4.34, J4.36, J5.1, R2.2, R3.2, RV1.3, SW1.2, SW2.2, SW3.2, U1.4 (V-), U1.5 (+), U3.2 (GND)
IN+: C3.2, J1.1 (In), R3.1, SW4.1 (A)
MOSI: J3.6, J4.20
unnamed: D1.3 (COM), R1.2, R2.1, R4.1, U1.3 (+)
unnamed: R4.2, RV1.2
unnamed: RV1.1, SW4.2 (B)
unnamed: C3.1, SW4.3 (C)
unnamed: R5.1, U1.1, U1.2 (-)
unnamed: U1.6 (-), U1.7
RES: J3.4, J4.14
SCK: J3.7, J4.18

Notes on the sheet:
Buttons
Power supply
Input BNC
Display
Analog frontend

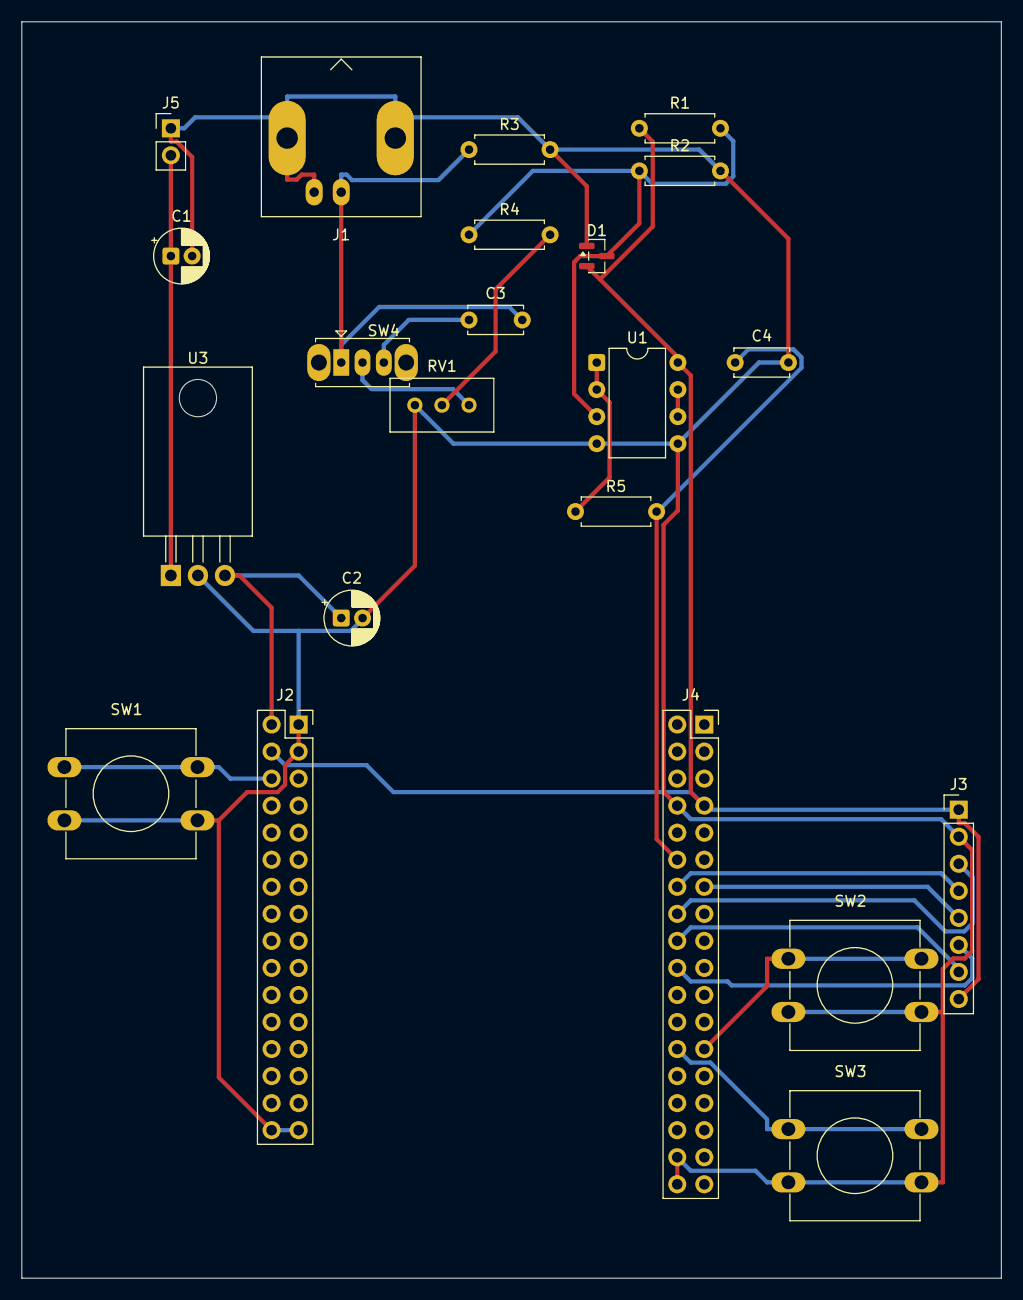
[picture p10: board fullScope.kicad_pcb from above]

Board: 2 copper layers, 92.0 x 118.0 mm, 22 parts (0 on the bottom side), 20 nets.

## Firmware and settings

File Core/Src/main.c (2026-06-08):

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
/* Includes ------------------------------------------------------------------*/
#include "main.h"
#include "adc.h"
#include "dma.h"
#include "spi.h"
#include "tim.h"
#include "usart.h"
#include "gpio.h"

/* USER CODE BEGIN Includes */
#include "scope.h"
#include "sandbox.h"
/* USER CODE END Includes */


void SystemClock_Config(void);
/**
  * @brief  The application entry point.
  * @retval int
  */
int main(void)
{

  /* MCU Configuration--------------------------------------------------------*/

  /* Reset of all peripherals, Initializes the Flash interface and the Systick. */
  HAL_Init();

  /* Configure the system clock */
  SystemClock_Config();

  /* Initialize all configured peripherals */
  MX_GPIO_Init();
  MX_DMA_Init();
  MX_ADC1_Init();
  MX_SPI1_Init();
  MX_TIM3_Init();
  MX_USART1_UART_Init();
  /* USER CODE BEGIN 2 */
  // Configure ST7735 Display Control Pins (PA2, PA3, PA4) as Output
  GPIO_InitTypeDef GPIO_InitStruct = {0};
  GPIO_InitStruct.Pin = ST7735_RES_Pin | ST7735_DC_Pin | ST7735_CS_Pin;
  GPIO_InitStruct.Mode = GPIO_MODE_OUTPUT_PP;
  GPIO_InitStruct.Pull = GPIO_NOPULL;
  GPIO_InitStruct.Speed = GPIO_SPEED_FREQ_HIGH;
  HAL_GPIO_Init(GPIOA, &GPIO_InitStruct);
  
  // Set CS and RES high by default
  HAL_GPIO_WritePin(GPIOA, ST7735_CS_Pin | ST7735_RES_Pin, GPIO_PIN_SET);

  // Configure Buttons (PB7, PB8, PB9) as Input with Pull-Up
  __HAL_RCC_GPIOB_CLK_ENABLE();
  GPIO_InitStruct.Pin = BTN1_Pin | BTN2_Pin | BTN3_Pin;
  GPIO_InitStruct.Mode = GPIO_MODE_INPUT;
  GPIO_InitStruct.Pull = GPIO_PULLUP;
  HAL_GPIO_Init(GPIOB, &GPIO_InitStruct);

  // Initialize the oscilloscope (starts the screen, ADC, timers, etc)
  scopeInit();
  
  // Initialize our custom sandbox!
  // sandboxInit(); // <--- Sandbox is currently disabled!
  /* USER CODE END 2 */

  /* Infinite loop */
  /* USER CODE BEGIN WHILE */
  while (1)
  {
    // Run the main oscilloscope update loop continuously
    scopeLoop(); 
    
    // Run our custom animation loop!
    // sandboxLoop(); // <--- Sandbox is currently disabled!
    /* USER CODE END WHILE */

    /* USER CODE BEGIN 3 */
  }
  /* USER CODE END 3 */
}

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


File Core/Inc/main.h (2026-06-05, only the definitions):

#define Button_Pin GPIO_PIN_15
#define Button_GPIO_Port GPIOD
#define LED_Pin GPIO_PIN_0
#define LED_GPIO_Port GPIOE
#define BTN1_Pin GPIO_PIN_7
#define BTN1_GPIO_Port GPIOB
#define BTN2_Pin GPIO_PIN_8
#define BTN2_GPIO_Port GPIOB
#define BTN3_Pin GPIO_PIN_9
#define BTN3_GPIO_Port GPIOB
#define ST7735_CS_Pin GPIO_PIN_4
#define ST7735_CS_GPIO_Port GPIOA
#define ST7735_DC_Pin GPIO_PIN_3
#define ST7735_DC_GPIO_Port GPIOA
#define ST7735_RES_Pin GPIO_PIN_2
#define ST7735_RES_GPIO_Port GPIOA

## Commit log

2026-07-06 feat: complete project restructure with README, PCB design, docs, and portfolio assets
    - Add professional README with breadboard prototype photos and PCB design showcase
    - Add KiCad PCB project (fullScope shield + pillScope_Shield), DRC-clean
    - Add Gerber manufacturing files (ready for JLCPCB)
    - Add high-quality assets: 3D raytraced renders, schematic PNG, copper SVGs
    - Add docs: HowItWorks.md, PCB_EXPLAINED.md, FABRICATION_TODO.md
    - Move helper scripts to scripts/ directory
    - Add .gitignore (build, KiCad backups, large JARs, Claude/CubeMX local files)
    - Remove stale root-level files (Frieren image, loose Python scripts)
    [fullScope-B_Courtyard.gbr, fullScope-B_Cu.gbl, fullScope-B_Fab.gbr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]
2026-07-09 docs: update FABRICATION_TODO with measured J4 spacing (38.1mm, +2.54mm fix needed)
2026-07-09 fix(pcb): shift J4 to 38.1mm, autoroute traces, update gerbers
    [fullScope-B_Courtyard.gbr, fullScope-B_Cu.gbr, fullScope-B_Fab.gbr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]
2026-07-13 feat(ui): ASCII art splash screen — no logo, just text + name + date
2026-09-09 fix(pcb): update gerber naming extensions, bundle KiCad project zip, and refresh DRC
    [fullScope-B_Cu.gbl, fullScope-B_Mask.gbs, fullScope-B_Paste.gbp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]

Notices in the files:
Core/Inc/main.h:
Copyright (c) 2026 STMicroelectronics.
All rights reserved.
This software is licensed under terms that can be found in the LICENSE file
